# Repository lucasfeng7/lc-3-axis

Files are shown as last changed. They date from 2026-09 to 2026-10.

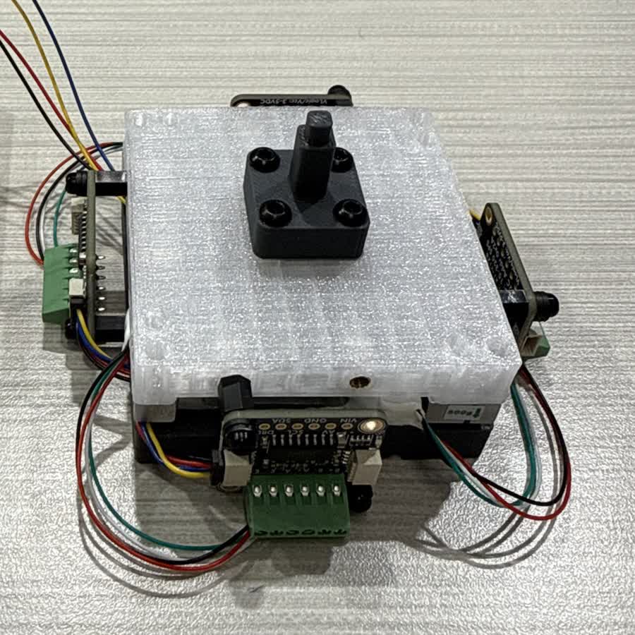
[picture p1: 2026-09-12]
docs/img/assembled.jpg

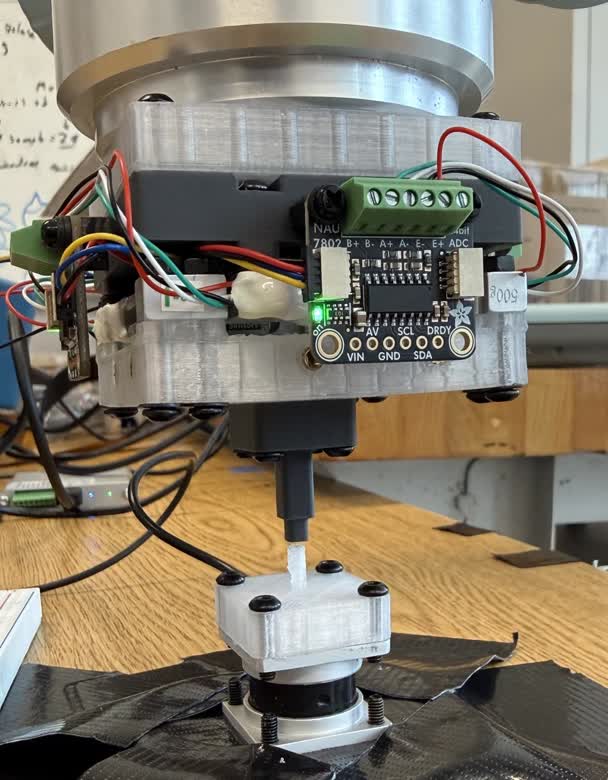
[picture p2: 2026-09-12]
docs/img/calib-optoforce.jpg

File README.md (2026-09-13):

# LC 3-Axis

An accurate three-axis force sensor assembled from off-the-shelf load cells,
with no custom compliant element.





Lucas Feng, Ariel Slepyan, Krishna Murthy, Nitish Thakor<br>
Johns Hopkins University

Presented at "Sensors and Actuators for Dexterous Manipulation: Bridging
Hardware and Application Needs," a workshop at IROS 2026 — Pittsburgh, PA.

---

## Overview

Affordable multi-axis force sensors are usually designed with a custom
compliant part, and the deformation of that part is measured after a load is
applied. Any creep, hysteresis, or thermal sensitivity in that part then
becomes a property of the finished sensor, so its accuracy depends on
operating temperature and load history in ways a single calibration cannot
capture. We instead developed a sensor using four commercial load cells that
are manufacturer-characterized to carry the full load. A single fitted
matrix maps their readings to force and accounts for assembly tolerances,
gain differences, and wiring polarity. The resulting sensor costs
\$116.55 in parts and has a 2.6–3.5 mN noise floor. Its output agrees
with a commercial reference to 1.0–2.5 % of full scale.

The full write-up, measurements, and comparison to prior work are in the
[paper](paper/lc-3-axis-iros2026.pdf) and on the
[project page](https://lucasfeng7.github.io/lc-3-axis/).

## Repository structure

```
.
├── cad/          SolidWorks source for the printed parts and top-level assembly
├── firmware/     Teensy 4.0 firmware (calibration, streaming, EEPROM storage)
├── paper/        Workshop paper (PDF)
├── media/        Demonstration video
├── docs/img/     Figures used by the project page
├── index.html    Project page (GitHub Pages)
├── CITATION.cff
└── LICENSE
```

## Bill of materials

Total **\$116.55** for the electromechanical parts below. Fasteners, cabling
and filament are excluded.

| Qty | Part | Role |
|---|---|---|
| 4 | TAL221 500 g bar load cell | the structure and the transducer, both |
| 4 | NAU7802 24-bit ADC breakout | one per cell, I²C address `0x2A` |
| 1 | TCA9548A I²C multiplexer | address `0x70`, A2:A0 to GND |
| 1 | Teensy 4.0 | reads the cells, applies the matrix, streams CSV |

Three part types are custom, and all three are FDM 3D printed.

| Part | Process | Notes |
|---|---|---|
| Upper plate | FDM, PLA | carries the tip — [`Top Plate.SLDPRT`](cad/Top%20Plate.SLDPRT) |
| Lower plate | FDM, PLA | bolts to the robot flange — [`Bottom Plate.SLDPRT`](cad/Bottom%20Plate.SLDPRT) |
| Interchangeable tip | FDM, PLA | sets contact height `h`, 38.6 mm here — [`Calibration Tip.SLDPRT`](cad/Calibration%20Tip.SLDPRT) |

No custom PCB. No machining. No cast or molded elastomer.

## CAD

SolidWorks source for the printed parts is in [`cad/`](cad/):

| File | Part |
|---|---|
| [`LC 3-Axis.SLDASM`](cad/LC%203-Axis.SLDASM) | top-level assembly |
| [`Top Plate.SLDPRT`](cad/Top%20Plate.SLDPRT) | upper plate |
| [`Bottom Plate.SLDPRT`](cad/Bottom%20Plate.SLDPRT) | lower plate |
| [`Calibration Tip.SLDPRT`](cad/Calibration%20Tip.SLDPRT) | interchangeable tip used for calibration, `h` = 38.6 mm |

The assembly references the load cells, converters and fasteners as
toolbox/purchased components, which are not included as separate files.

## How it works

Four vertical load cells connect the two 3D-printed plates in a square. Each
senses compression along the vertical axis, and together they respond to
`Fz`, `Mx`, and `My`. A lateral force is recovered from its moment about the
cell plane. For a contact at `(xc, yc)` and height `h`,

```
My = -Fx·h + Fz·xc
Mx =  Fy·h - Fz·yc
```

The contact location must therefore be known. This suits a probe with fixed
tip geometry rather than a general-purpose contact plate.

We tare each channel before loading to remove the assembly preload and the
weight of the parts above the cells. A fitted 3×4 matrix with a bias
converts the four tared counts into `(Fx, Fy, Fz)`. The same fit absorbs
placement error, cell-to-cell gain variation, and wiring polarity. Firmware
identifies the multiplexer channel used by each converter, so the physical
cell order does not matter.

## Firmware

[`firmware/lc_3_axis.ino`](firmware/lc_3_axis.ino) runs on the Teensy 4.0. It
discovers the multiplexer channels at boot, stores the calibration matrix and
the discovered channel map together in EEPROM, and refuses to load a
calibration whose map does not match the hardware present.

Libraries are Adafruit NAU7802 and Adafruit BusIO. I²C runs at 400 kHz on pins
18 and 19, with each ADC at gain 128 and 320 SPS.

Serial at 115200, newline endings. Output is plain CSV in newtons.

```
0.0142,-0.0031,1.9847
```

| key | does |
|---|---|
| `t` | re-tare, since zero drifts with temperature and the matrix does not |
| `r` | stream Fx, Fy, Fz |
| `p` | pause |
| `d` | also show the four raw cell counts |
| `u` | switch newtons and gram-force |

Lines beginning `#` are messages rather than data, so filter them when parsing.

## Calibrating

We calibrate against known masses rather than against another force sensor.
For each lateral axis, the sensor is clamped axis-horizontal at a bench edge
and known masses are hung from the tip, so gravity loads the sensing axis
perpendicular by construction. For the axial axis, a known mass is stacked
directly on the tip. The 3×4 calibration matrix is then fit against
the tared cell counts recorded at each load.

Validation against an independent reference is optional. Ours used an
OptoForce carried in series with the sensor on a UR5e, so both instruments
saw the same contact force.

## Citation

```bibtex
@inproceedings{feng2026lc3axis,
  title     = {An Accurate Three-Axis Force Sensor Assembled with Readily Available Off-the-Shelf Components with No Designed Compliant Element},
  author    = {Feng, Lucas and Slepyan, Ariel and Murthy, Krishna and Thakor, Nitish},
  booktitle = {IROS 2026 Workshop on Sensors and Actuators for Dexterous Manipulation},
  year      = {2026}
}
```

## License

MIT. See [LICENSE](LICENSE).

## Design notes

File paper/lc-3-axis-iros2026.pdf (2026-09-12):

## An Accurate Three-Axis Force Sensor Assembled with Readily Available Off-the-Shelf Components with No Designed Compliant Element

Lucas Feng, Ariel Slepyan, Krishna Murthy and Nitish Thakor Johns Hopkins University
{lfeng22, aslepya1, kmj, nitish}@jhu.edu

Abstract—Affordable multi-axis force sensors are usually designed with a custom compliant part, and the deformation of that part is measured after a load is applied. Any creep, hysteresis, or thermal sensitivity in that part then becomes a property of the finished sensor. Its accuracy then depends on operating temperature and load history in ways a single calibration cannot capture. We instead developed a sensor using four commercial load cells that are manufacturer-characterized to carry the full load. On top of the mechanical design, one fitted matrix that maps readings to force accounts for assembly tolerances, gain differences, and wiring polarity. The resulting three-axis sensor costs under $120 and has a 2.6–3.5 mN noise floor. Off-axis leakage remains below 1 %, and lateral hysteresis remains below 0.5 % of span. After one scale factor, its output agrees with a commercial reference to 1.0–2.5 % of full scale across more than 300,000 in-contact samples. The design suits tools whose contact point is known and makes an accurate three-axis sensor accessible to any research lab with a 3D printer.

I. INTRODUCTION
Force sensing is critical in any task where a robot meets a surface it cannot fully model. Commercial multi-axis sensors do this well but cost tens of thousands of dollars [1], which has pushed a research effort toward cheaper designs.
Those low-cost designs have used optical readout [2], cameras and fiducials [1], capacitance [3], and light transmitted through an elastomer [4]. In each case an inexpensive sensor measures a compliant structure built for that device. The structure determines range and sensitivity, and it also adds creep, hysteresis, and temperature dependence. These effects are seldom characterized in full. Hysteresis is sometimes reported, but creep and temperature dependence usually are not, so a user cannot predict the error under a sustained load, under load cycling, or at a different operating temperature.

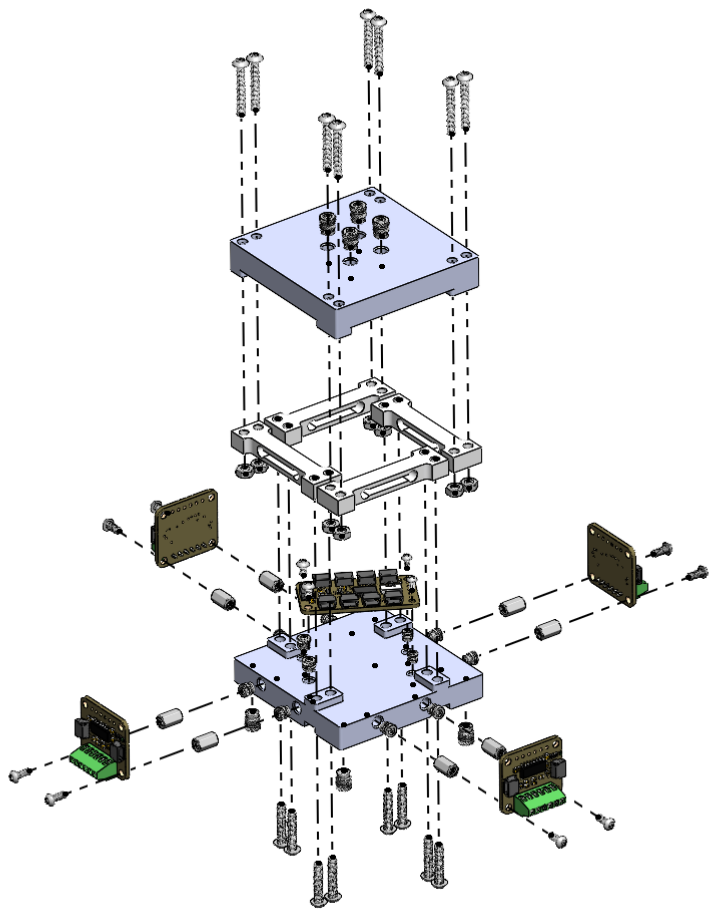
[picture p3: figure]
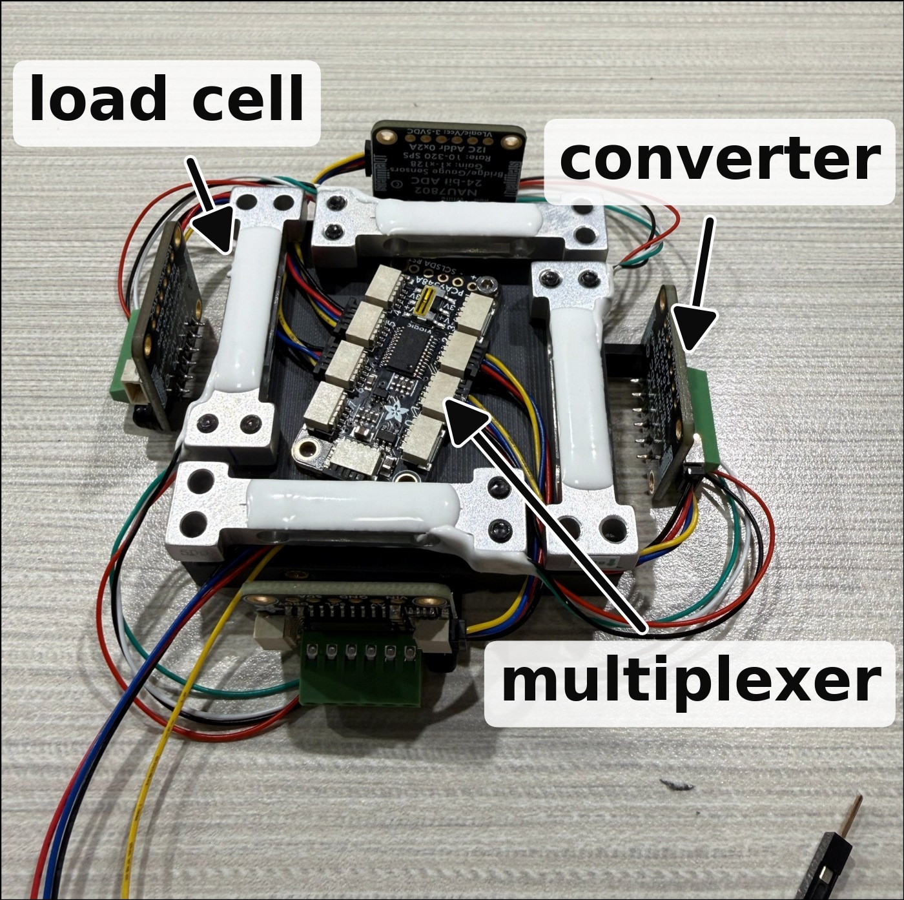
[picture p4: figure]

Fig. 1. The sensor as designed and as built. On the left, an exploded view of the body, with the interchangeable tip and the microcontroller omitted. On the right, the four load cells that form the structure, with the converters on the perimeter and the I²C multiplexer at the center.

The four-cell arrangement already exists in a design by Chua and Okamura, which places four commercial pointcontact cells around a PCB perimeter [5]. That design needs a custom PCB, which makes it far less readily available and much more expensive. Ours keeps the cost low and the error terms quantifiable while using only off-the-shelf parts. The load cells serve as both beams and transducers. Their beam geometry, strain-gauge placement and bridge compensation are set at manufacture, and the creep and temperature behavior that follows is specified on the datasheet [6], so no separate part needs its own characterization.

II. METHOD

A. Sensor Structure
Four TAL221 500 g bar load cells connect the two 3D-printed plates in a square (Fig. 1). Each senses compression along the vertical axis. Together they respond to Fz, Mx, and My. The remaining combination is the self-stress mode, a pattern of internal cell forces that cannot be produced by an external load.
Each load cell has its own NAU7802 converter, interleaved through an I²C multiplexer for an aggregate output of about 1200 Hz. The multiplexer connects to a Teensy 4.0, though any reasonably capable microcontroller would serve.
A lateral force is recovered from its moment about the cell plane. For a contact at (xc, yc) and height h, My = −Fxh + Fzxc and Mx = Fyh − Fzyc. The contact location must therefore be known. For the tests reported here, the contact face lies 38.6 mm above the cell mid-plane.
We tare each channel before loading to remove the assembly preload and the weight of the parts above the cells. A fitted 3 × 4 matrix with a bias converts a four-entry vector of tared counts into (Fx, Fy, Fz). The same fit absorbs placement error, cell-to-cell gain variation, polarity, and cross-coupling. Firmware identifies the multiplexer channel used by each converter, so the physical cell order does not matter.

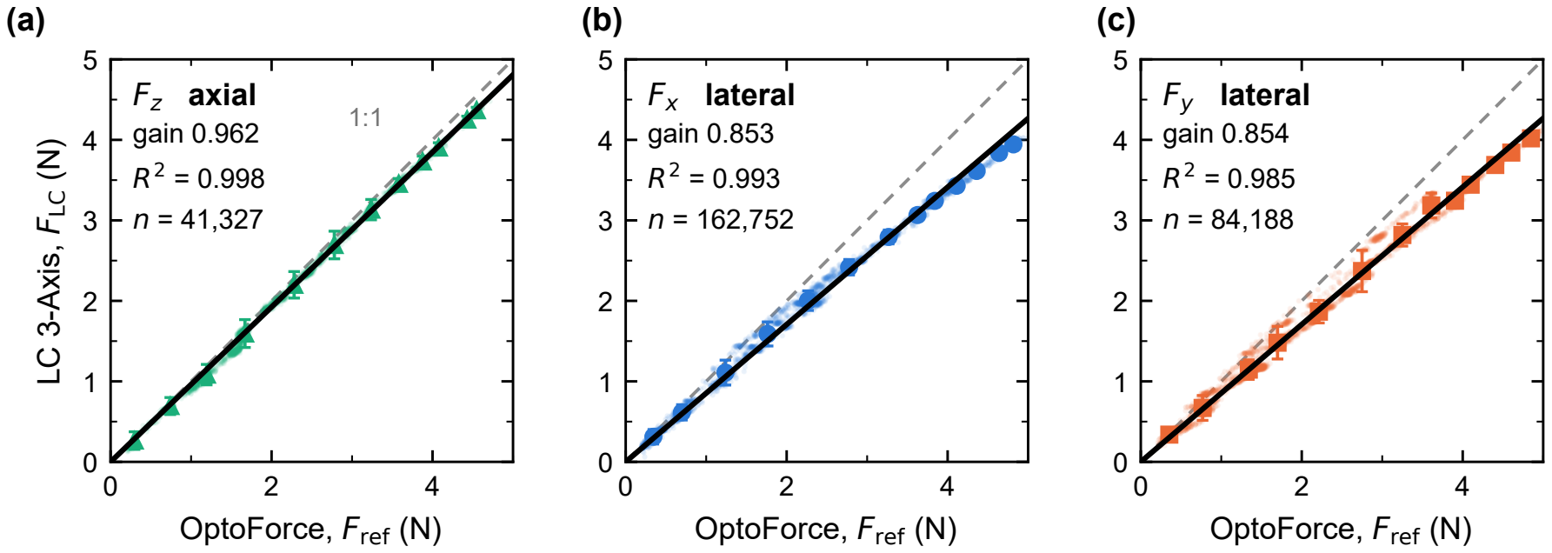
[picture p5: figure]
OptoForce, Fref (N); LC 3-Axis, FLC (N); Fz axial gain 0.962 R; Fx lateral gain 0.853 R; Fy lateral gain 0.854 R

Fig. 2. Response against the OptoForce reference with both instruments in series on the same rig. Dashed gray is the 1:1 line and black is a least-squares fit through the origin. Markers are slice means with their standard deviation. The gains and R²
shown are for the magnitude fit, which is frame-invariant. The per-axis component values quoted in the text are gains of 0.953, 0.865 and 0.873 at r

2 ≥ 0.993. The spread below 1 N in (a) is the reference’s own 0.0319 N quantization rather than sensor noise.

TABLE I
BENCH BEHAVIOR, CALIBRATED RANGE 0–4.9 N
| Fx | Fy | Fz
Leave-one-out error (N) | 0.0431 | 0.0330 | 0.0357
Noise floor, 1σ (mN) | 3.2 | 3.5 | 2.6
On-axis decoupling (%) | 100.1 | 99.7 | 99.6
Hysteresis (% of span) | 0.111 | 0.421 | 1.112

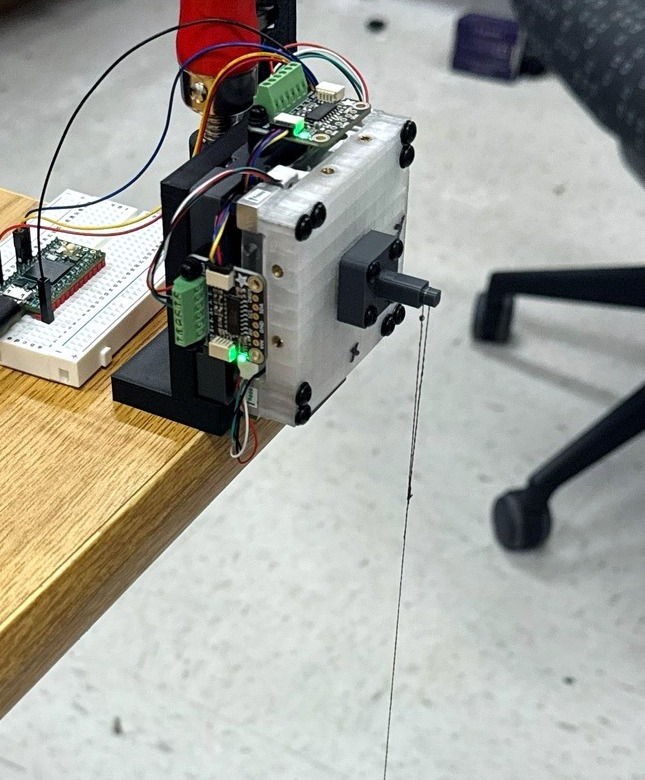
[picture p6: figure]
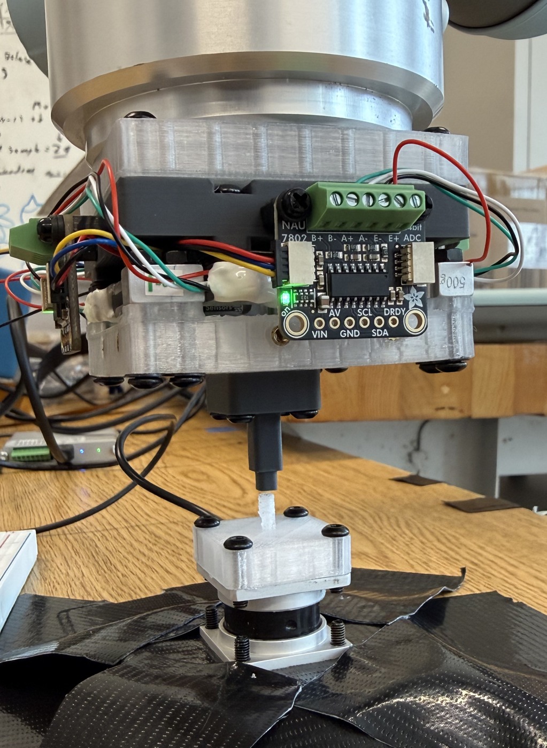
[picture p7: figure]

Fig. 3. The two calibrations. Left, the sensor clamped axis-horizontal at the bench edge with known masses hanging from the tip, so gravity loads it perpendicular to the sensing axis. Right, the two instruments in series on the UR5e, the sensor on the flange and the OptoForce below it, so each carries the same force.

B. Fabrication
Only three of the seventeen part types are custom. They are two FDM 3D-printed PLA plates and an interchangeable printed tip. The load cells, converters, multiplexer, and microcontroller cost $116.55 in total. Fasteners, cabling, and filament are excluded. The bill of materials, firmware and calibration procedure are at https://github.com/lucasfeng7/lc-3-axis.

III. EXPERIMENT

A. Sensor Characterization
We calibrated against known masses rather than another force sensor (Fig. 3). For each lateral axis the sensor was clamped horizontal, so gravity acted perpendicular to the axis being loaded.
Table I reports leave-one-out error, which stays below 0.9 % of range on every axis. Residuals measured in sample are 2.2 times smaller. On-axis decoupling is close to a full response on every axis, and the Fx entry sits just above it because of a small overshoot in the estimate. Leakage onto the other two axes stays below 1 %. Hysteresis is 0.111 % and 0.421 % of span laterally.
We applied three overloads of 19.9–28.7 N against the 19.6 N limit. After each, the unloaded output returned to within 0.05 N of zero. A different load-cell rating changes the range without changing the design.
B. Independent Validation
For validation, the UR5e carried two independently calibrated instruments in a serial stack (Fig. 3). Their coordinate frames were aligned with an orthogonal transform. The data contain 344,424 in-contact samples. The responses and fits appear in Fig. 2.
Allowing one scale factor per axis, the readings then sit within 0.1137 N of the reference on Fx and 0.1211 N on Fy,

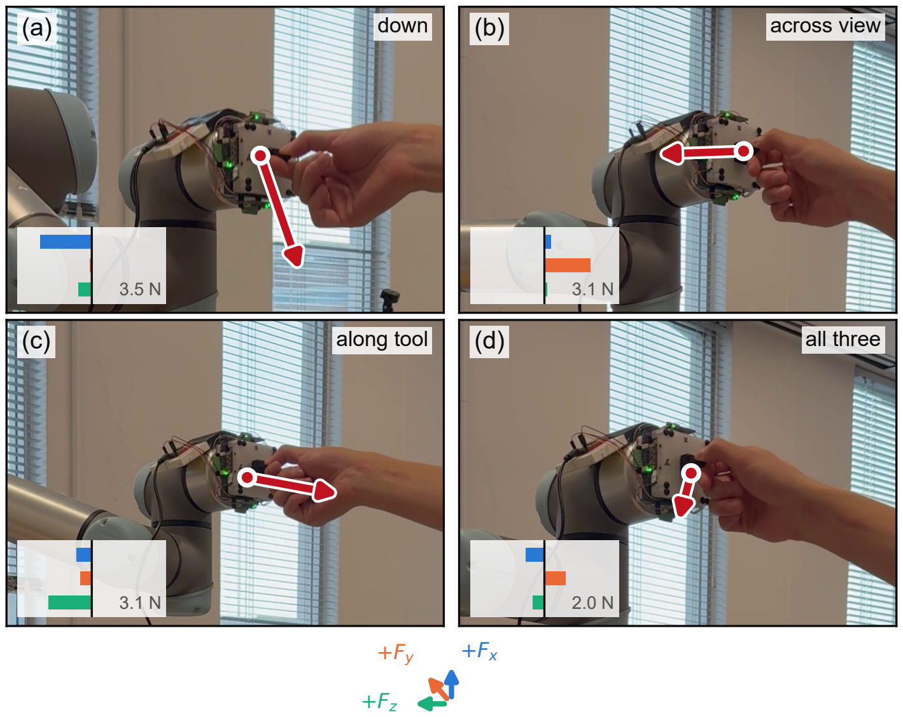
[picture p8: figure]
(a) down; (b) across view; (c) along tool; (d) all three

Fig. 4. The sensor driving admittance hand-guiding on the UR5e. Four instants from one run, with the components measured at each instant inset on a common 4.9 N scale, colored as the triad at the right. The red arrow is the measured force projected into the image from the contact point, so its length is foreshortened. Fy and Fz project within 1° of each other here, so the arrow gives the direction of a push but not its split between those two axes, which the bars carry. Panel (a) is a push down, (b) across the view, (c) along the tool, and (d) loads all three axes at once.

which is 2.32 % and 2.47 % of the 4.9 N range. The two rise together in a straight line, at r

2 ≥ 0.993. For Fz we pressed in steps of increasing force along the tool axis, where the readings sit within 0.0480 N, or 0.98 %, at r

2 = 0.998. The
scale factors themselves are 0.865 and 0.873 laterally and 0.953 axially. What separates them is scale, not scatter and not nonlinearity. The likely cause is that the robotic arm was controlled manually during the comparison, which varies the contact height and therefore the lever arm.
Even so, these figures match or exceed the closest comparable design. Both are the RMS disagreement with an independent reference after per-axis calibration constants are fitted. Ours are 0.1137 and 0.1211 N laterally and 0.0480 N axially. Chua and Okamura report 0.105 to 0.146 N laterally and 0.064 to 0.126 N axially, the spread being across the two units they built [5].
C. Sensor Applications
Finally, we used the sensor for admittance hand-guiding. In this control mode, the measured contact force commands the robot’s Cartesian velocity. The loop runs at 199.8 Hz (Fig. 4). It responds to single-axis pushes and to simultaneous loading of all three axes, which confirms that the sensor is fast and accurate enough to close a control loop on a moving robot rather than only on a bench.

IV. CONCLUSION
In this study we presented a three-axis force sensor which leverages four load cells as the structure. The sensor does not need a custom PCB and is simple to assemble, and it agrees with a commercial reference to 1.0–2.5 % of full scale. It matches or exceeds the accuracy of the closest comparable design, which makes it an affordable and easy-to-implement option for research labs that need accurate three-axis force sensing.

REFERENCES

[1] R. Ouyang and R. D. Howe, “Low-cost fiducial-based 6-axis force-torque sensor,” in IEEE International Conference on Robotics and Automation (ICRA), 2020, pp. 1–7.
[2] N. Hendrich, F. Wasserfall, and J. Zhang, “3D printed low-cost force-torque sensors,” IEEE Access, vol. 8, pp. 140 569–140 585, 2020.
[3] H. Choi et al., “CoinFT: A coin-sized, capacitive 6-axis force torque sensor,” arXiv preprint arXiv:2503.19225, 2025.
[4] A. El-Azizi, S. Islam, P. Piacenza, I. Kymissis, and M. Ciocarlie, “A compact, low-cost force and torque sensor for robot fingers with LEDbased displacement sensing,” arXiv preprint arXiv:2410.03481, 2024.
[5] Z. Chua and A. M. Okamura, “A modular 3-degrees-of-freedom force sensor for robot-assisted minimally invasive surgery research,” Sensors, vol. 23, no. 11, p. 5230, 2023.
[6] HTC Sensor, “TAL221 miniature load cell datasheet,” https://cdn.sparkfun.com/assets/9/9/a/f/3/TAL221.pdf, (https://cdn.sparkfun.com/assets/9/9/a/f/3/TAL221.pdf) 2024, creep ±0.05 % of full scale over 3 min, compensated temperature range −20 to +60 °C.

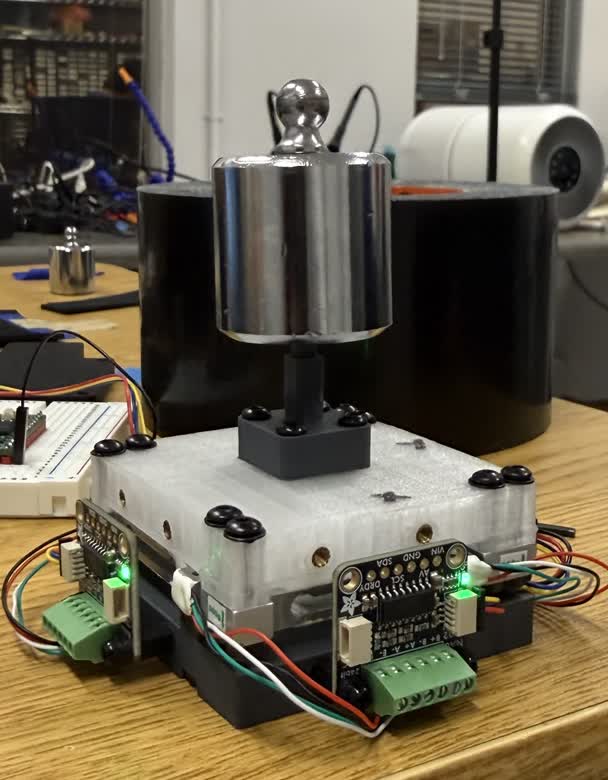
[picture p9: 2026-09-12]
docs/img/calib-axial.jpg

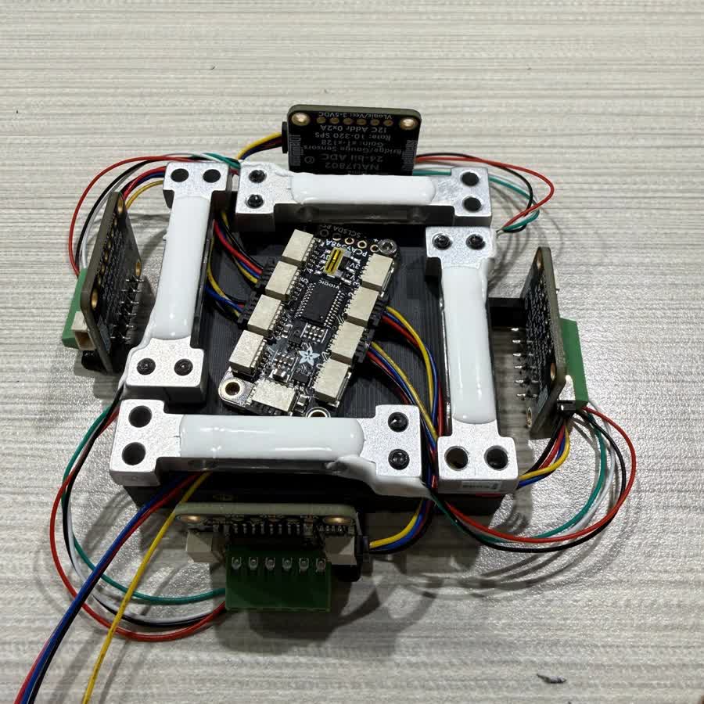
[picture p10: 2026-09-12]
docs/img/internals.jpg

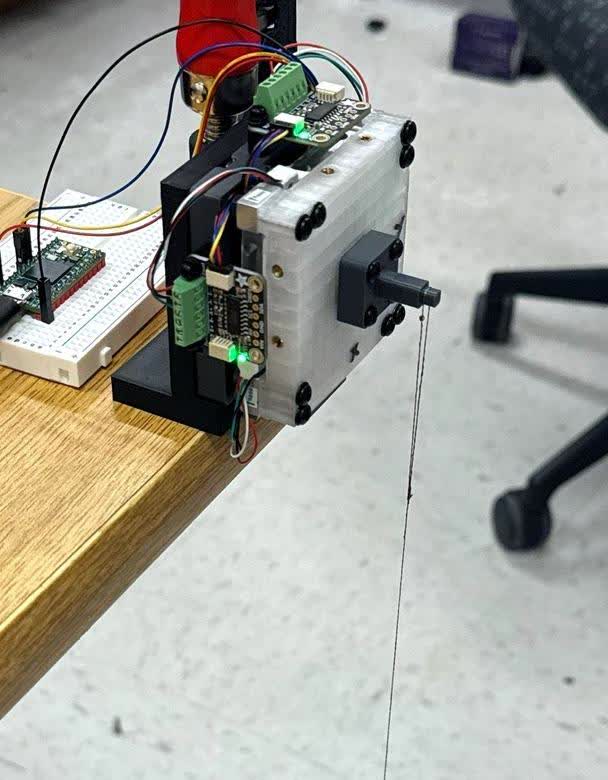
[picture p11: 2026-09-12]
docs/img/calib-deadweight.jpg

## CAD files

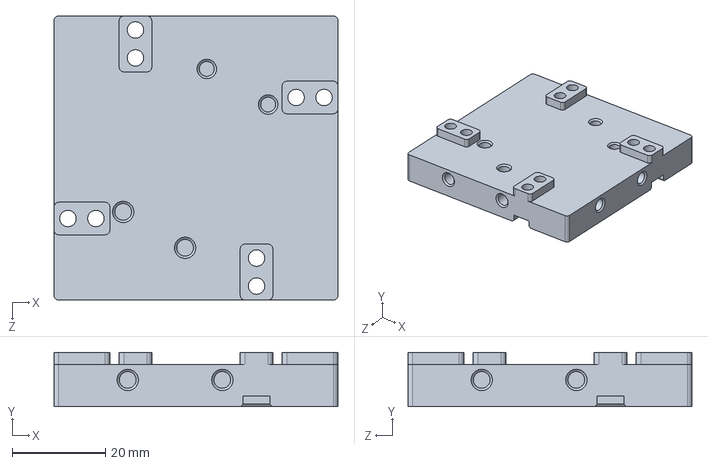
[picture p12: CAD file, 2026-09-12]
cad/Bottom Plate.SLDPRT
61.0 x 11.6 x 61.0 mm

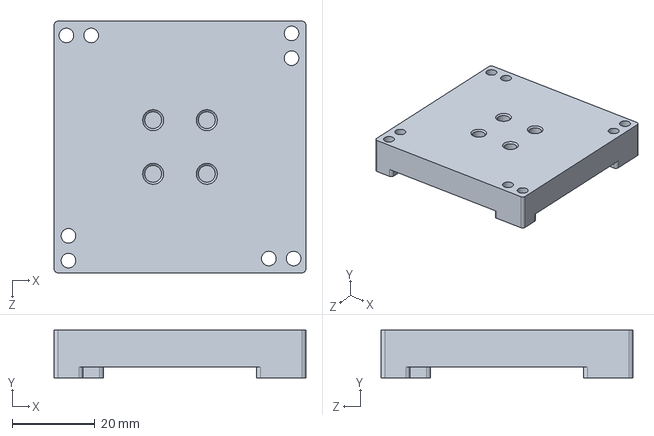
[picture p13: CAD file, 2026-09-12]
cad/Top Plate.SLDPRT
61.0 x 11.6 x 61.0 mm

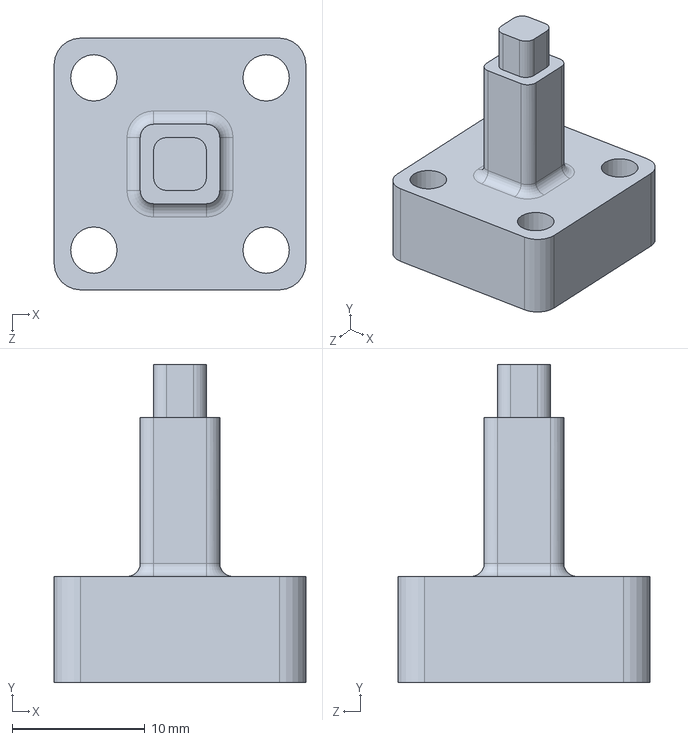
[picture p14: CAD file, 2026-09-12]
cad/Calibration Tip.SLDPRT
19.0 x 24.0 x 19.0 mm

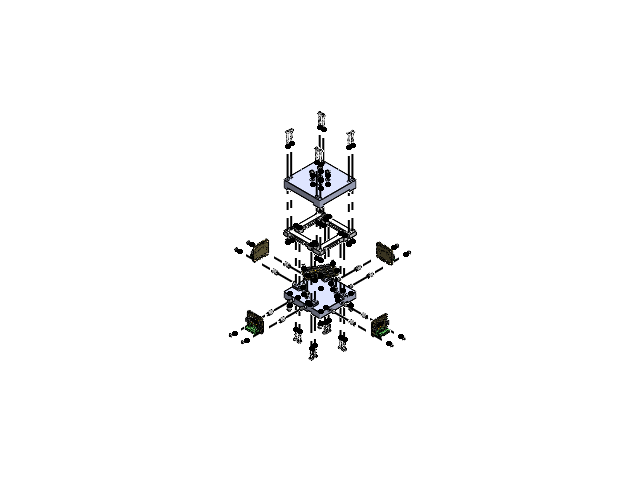
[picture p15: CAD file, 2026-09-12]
cad/LC 3-Axis.SLDASM
Bottom Plate Smaller
5626 PCA9548 Stemma
m2.5 x 10
m2 x 2
4538 NAU7802 Rev C x 4
m3_heat_set_insert x 8
92319A118_Nylon 6-6 Plastic Hex Standoff x 8
91239A811_Button Head Hex Drive Screw x 8
91239A755_Button Head Hex Drive Screw x 8
91239A753_Button Head Hex Drive Screw x 2
91239A703_Button Head Hex Drive Screw x 2
Top Plate Smaller
91239A122_Button Head Hex Drive Screw x 8
90592A085_Steel Hex Nut x 8
TAL221 500g load cell v1 x 4

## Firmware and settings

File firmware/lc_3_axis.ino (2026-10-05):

/*
 * LC 3-Axis force sensor firmware
 *
 * Target: Teensy 4.0 with a TCA9548A I2C multiplexer and four NAU7802
 * 24-bit ADCs, one per 500 g load cell.
 *
 * The four load cells provide Fz and the bending moments used to infer Fx
 * and Fy. Calibration fits a single 3x4 linear map from tared cell counts
 * to (Fx, Fy, Fz), absorbing cell gain, polarity, placement, and coupling.
 *
 * Calibration samples are zero-bracketed to reduce thermal drift. Lateral
 * calibration assumes the load is applied at the calibrated tip height;
 * off-center normal loads also generate moment and cannot be distinguished
 * from lateral force by this geometry.
 *
 * Multiplexer channels are discovered at startup and stored with calibration.
 * Serial interface: 115200 baud, newline terminated. Send 'h' for help.
 */


#include <Wire.h>
#include <EEPROM.h>
#include <Adafruit_NAU7802.h>

// Config
#define TCA_ADDR      0x70            // TCA9548A (A2:A0 = GND)
#define NAU_ADDR      0x2A            // NAU7802, fixed
#define NUM_CELLS     4
#define NPAR          5               // 4 count coefficients + 1 bias

#define I2C_HZ        400000          // within spec for both devices
#define ADC_RATE      NAU7802_RATE_320SPS
#define ADC_GAIN      NAU7802_GAIN_128

#define G0            9.80665f        // m/s^2
#define CELL_RATING_G 500.0f          // per cell; loads above the array rating are refused

#define WARMUP_DISCARD   8            // settling samples discarded after init
#define READ_TIMEOUT_MS  250
#define FRAME_TIMEOUT_MS 50           // emit a frame even if a cell stops updating
#define ACQ_TIMEOUT_MS   20000        // timeout for one averaged block

#define DEF_CAL_SAMPLES  512          // per cell, per read (512 @ 320 SPS = 1.6 s)
#define MIN_CAL_SAMPLES  64
#define MAX_CAL_SAMPLES  4096
#define NOISE_SAMPLES    512          // used at tare to measure the noise floor
#define STABLE_K         3.0          // reject a block noisier than K * tare noise
#define DRIFT_K          4.0          // reject a block trending > K sigma of its mean
#define ZERO_DRIFT_K     6.0          // warn if the bracket's two zeros disagree
#define ACQ_RETRIES      3
#define SETTLE_MS        1500         // wait for initial load-cell creep before sampling

#define MAX_SAMPLES   24              // bounded by EEPROM size, see EEPROM_BYTES
#define COUNT_SCALE   1e-6            // counts are ~1e6; scaled for conditioning
#define RIDGE_REL     1e-6            // ridge lambda, relative to mean diagonal

#define EEPROM_MAGIC  0x3A01          // change whenever the stored layout changes
#define EEPROM_ADDR   0

// State
Adafruit_NAU7802 nau;

uint8_t muxChan[NUM_CELLS];           // discovered at boot, stored with the calibration
uint8_t nFound    = 0;
int8_t  curChan   = -1;               // currently selected channel, to skip redundant writes

double  zeroCount[NUM_CELLS];         // live tare, raw counts
double  noiseSd[NUM_CELLS];           // unloaded standard deviation at tare, counts

int32_t rawCount[NUM_CELLS];          // newest streamed sample
bool    hasFresh[NUM_CELLS];

// Fx, Fy, Fz = M * counts + bias, in newtons.
// Defaults to the nominal square layout, so an uncalibrated board still
// streams output with the expected sign pattern.
float M[3][NUM_CELLS] = {
  { 1, -1, -1,  1},                   // Fx  (nominal)
  { 1,  1, -1, -1},                   // Fy  (nominal)
  { 1,  1,  1,  1},                   // Fz  = sum
};
float bias[3] = {0, 0, 0};
bool  fitted  = false;

// Types
// Keep these declarations above the first function definition because the
// Arduino build generates prototypes before compiling the sketch.

struct Sample {
  float   c[NUM_CELLS];               // zero-bracketed counts
  float   f[3];                       // applied force, newtons
  uint8_t axis;                       // 0=X 1=Y 2=Z, for reporting only
};
Sample  samples[MAX_SAMPLES];
uint8_t nSamples = 0;

// One averaged acquisition, with the statistics used by the stability check.
struct Block {
  double mean[NUM_CELLS];
  double sd[NUM_CELLS];
  double drift[NUM_CELLS];            // second-half mean minus first-half mean
};

struct FitReport {
  double rms[3];        // in-sample RMS residual, N
  double loo[3];        // leave-one-out RMS residual, N
  double worst[3];      // largest in-sample residual, N
  double ev[NUM_CELLS]; // eigenvalues of the scaled count Gram matrix, descending
  bool   ok;
};
FitReport lastFit;

// EEPROM footprint; the Teensy 4.0 provides 1080 bytes.
static const int EEPROM_BYTES = sizeof(uint16_t) + NUM_CELLS + 1 + 1
                              + NUM_CELLS * (int)sizeof(float)
                              + 3 * NUM_CELLS * (int)sizeof(float)
                              + 3 * (int)sizeof(float)
                              + MAX_SAMPLES * (int)sizeof(Sample);
static_assert(EEPROM_BYTES <= 1080, "calibration will not fit in Teensy 4.0 EEPROM");

bool     streaming  = false;
bool     showCells  = false;
bool     showStamp  = false;
bool     useNewton  = true;           // false = gram-force
float    emaAlpha   = 1.0f;           // 1 = unfiltered
uint16_t calSamples = DEF_CAL_SAMPLES;

uint32_t lastFrameMs = 0;

// Utilities
// Float formatter. %f is not reliable with newlib-nano on Teensy, and
// formatting into a buffer lets each line go out in a single Serial.write.
int fmtF(char *b, double v, int dec) {
  int i = 0;
  if (isnan(v))       { b[0] = 'n'; b[1] = 'a'; b[2] = 'n'; return 3; }
  if (fabs(v) > 1e9)  { b[0] = v < 0 ? '-' : '+'; b[1] = b[2] = b[3] = '9'; return 4; }
  if (v < 0) { b[i++] = '-'; v = -v; }
  double round = 0.5;
  for (int k = 0; k < dec; k++) round *= 0.1;
  v += round;
  uint32_t ip = (uint32_t)v;
  double   fp = v - ip;
  char t[12];
  int  n = 0;
  if (!ip) t[n++] = '0';
  while (ip) { t[n++] = '0' + ip % 10; ip /= 10; }
  while (n)  b[i++] = t[--n];
  if (dec > 0) {
    b[i++] = '.';
    for (int k = 0; k < dec; k++) {
      fp *= 10;
      int d = (int)fp;
      if (d > 9) d = 9;
      b[i++] = '0' + d;
      fp -= d;
    }
  }
  return i;
}

// Right-aligned float in a fixed-width column.
void pf(double v, int width, int dec) {
  char b[32];
  int n = fmtF(b, v, dec);
  for (int k = n; k < width; k++) Serial.print(' ');
  Serial.write(b, n);
}

float toDisplay(float newtons) { return useNewton ? newtons : newtons * 1000.0f / G0; }
const __FlashStringHelper *unitName() { return useNewton ? F("N") : F("gf"); }

// Mux
bool tcaSelect(uint8_t channel) {
  if (curChan == (int8_t)channel) return true;   // already selected
  Wire.beginTransmission(TCA_ADDR);
  Wire.write(1 << channel);
  if (Wire.endTransmission() != 0) { curChan = -1; return false; }
  curChan = channel;
  return true;
}

// ADC
bool initNAU() {
  if (!nau.begin(&Wire)) return false;
  nau.setLDO(NAU7802_3V0);
  nau.setGain(ADC_GAIN);
  nau.setRate(ADC_RATE);
  // Gain and rate changes invalidate the internal calibration, so redo it.
  nau.calibrate(NAU7802_CALMOD_INTERNAL);
  nau.calibrate(NAU7802_CALMOD_OFFSET);
  for (uint8_t i = 0; i < WARMUP_DISCARD; i++) {
    uint32_t t0 = millis();
    while (!nau.available()) if (millis() - t0 > READ_TIMEOUT_MS) return true;
    nau.read();
  }
  return true;
}

// Discover NAU7802 devices in mux-channel order. Store the channel map with
// calibration so missing hardware cannot silently change cell indexing.
bool discoverCells(bool verbose) {
  curChan = -1;
  Wire.beginTransmission(TCA_ADDR);
  if (Wire.endTransmission() != 0) {
    Serial.print(F("# TCA9548A NOT found at 0x")); Serial.println(TCA_ADDR, HEX);
    Serial.println(F("# check SDA/SCL (Teensy 4.0: 18/19), 3V3, GND, pull-ups, A0-A2"));
    nFound = 0;
    return false;
  }

  nFound = 0;
  for (uint8_t ch = 0; ch < 8 && nFound < NUM_CELLS; ch++) {
    if (!tcaSelect(ch)) continue;
    delay(2);
    Wire.beginTransmission(NAU_ADDR);
    if (Wire.endTransmission() != 0) continue;
    if (!initNAU()) continue;
    muxChan[nFound] = ch;
    zeroCount[nFound] = 0;
    noiseSd[nFound]   = 0;
    rawCount[nFound]  = 0;
    nFound++;
  }

  if (verbose) {
    Serial.print(F("# found ")); Serial.print(nFound);
    Serial.print(F(" of ")); Serial.print(NUM_CELLS); Serial.print(F(" cells on mux ch"));
    for (uint8_t c = 0; c < nFound; c++) { Serial.print(' '); Serial.print(muxChan[c]); }
    Serial.println();
    if (nFound < NUM_CELLS)
      Serial.println(F("# ! all four cells are required for 3-axis output - 'i' to rescan"));
  }
  for (uint8_t c = 0; c < NUM_CELLS; c++) hasFresh[c] = (c >= nFound);
  lastFrameMs = millis();
  return nFound == NUM_CELLS;
}

// Acquisition
// Acquire an averaged block using round-robin polling so all cells cover the
// same time window. Also compute per-cell noise and intra-block drift.
bool acquire(Block &blk, uint16_t want) {
  if (nFound == 0) return false;
  double   sum[NUM_CELLS] = {0}, sum2[NUM_CELLS] = {0}, firstSum[NUM_CELLS] = {0};
  double   ref[NUM_CELLS] = {0};
  uint16_t n[NUM_CELLS]   = {0};
  const uint16_t half = want / 2;
  uint32_t t0 = millis();

  for (;;) {
    bool done = true;
    for (uint8_t c = 0; c < nFound; c++) {
      if (n[c] >= want) continue;
      done = false;
      if (!tcaSelect(muxChan[c]) || !nau.available()) continue;
      double v = (double)nau.read();
      if (n[c] == 0) ref[c] = v;             // offset by the first reading before
      double d = v - ref[c];                 // squaring to preserve precision in sum2
      sum[c]  += d;
      sum2[c] += d * d;
      if (n[c] < half) firstSum[c] += d;
      n[c]++;
    }
    if (done) break;
    if (millis() - t0 > ACQ_TIMEOUT_MS) return false;
  }

  for (uint8_t c = 0; c < nFound; c++) {
    double m  = sum[c] / n[c];
    double var = sum2[c] / n[c] - m * m;
    blk.mean[c] = ref[c] + m;
    blk.sd[c]   = var > 0 ? sqrt(var) : 0;
    double f = firstSum[c] / half;
    double s = (sum[c] - firstSum[c]) / (n[c] - half);
    blk.drift[c] = s - f;
  }
  return true;
}

// Retry averaged reads while the signal is settling. Stability thresholds are
// relative to the noise floor measured during tare.
bool acquireStable(Block &blk, const __FlashStringHelper *what) {
  delay(SETTLE_MS);                    // allow load-cell creep to settle
  for (uint8_t attempt = 1; attempt <= ACQ_RETRIES; attempt++) {
    if (!acquire(blk, calSamples)) {
      Serial.println(F("# ! a cell stopped responding - 'i' to rescan"));
      return false;
    }
    int8_t noisy = -1, moving = -1;
    for (uint8_t c = 0; c < nFound; c++) {
      double floorSd = noiseSd[c] > 1 ? noiseSd[c] : 1;
      // K times the standard error of the difference between half-block means.
      double driftLim = DRIFT_K * blk.sd[c] * sqrt(2.0 / (calSamples / 2));
      if (driftLim < 0.5) driftLim = 0.5;
      if (blk.sd[c] > STABLE_K * floorSd)          noisy  = c;
      if (fabs(blk.drift[c]) > driftLim)           moving = c;
    }
    if (noisy < 0 && moving < 0) return true;

    Serial.print(F("# still settling ("));
    Serial.print(what);
    if (noisy >= 0) {
      Serial.print(F(", cell ")); Serial.print(noisy);
      Serial.print(F(" noise ")); pf(blk.sd[noisy], 0, 0);
      Serial.print(F(" vs ")); pf(STABLE_K * (noiseSd[noisy] > 1 ? noiseSd[noisy] : 1), 0, 0);
      Serial.print(F(" counts"));
    }
    if (moving >= 0) {
      Serial.print(F(", cell ")); Serial.print(moving);
      Serial.print(F(" drifting ")); pf(blk.drift[moving], 0, 0);
      Serial.print(F(" counts"));
    }
    Serial.print(F(") - retry ")); Serial.print(attempt);
    Serial.print('/'); Serial.println(ACQ_RETRIES);
  }
  Serial.println(F("# ! never settled - taking it anyway, treat this point with suspicion"));
  return true;
}

// Streaming
void pollCells() {
  for (uint8_t c = 0; c < nFound; c++) {
    if (!tcaSelect(muxChan[c])) continue;
    if (nau.available()) { rawCount[c] = nau.read(); hasFresh[c] = true; }
  }
}

bool frameReady() {
  for (uint8_t c = 0; c < NUM_CELLS; c++) if (!hasFresh[c]) return false;
  return true;
}

void applyMatrix(const float c[NUM_CELLS], float f[3]) {
  for (uint8_t r = 0; r < 3; r++) {
    double a = bias[r];
    for (uint8_t i = 0; i < NUM_CELLS; i++) a += (double)M[r][i] * c[i];
    f[r] = (float)a;
  }
}

// Apply the matrix and the EMA filter, then send one CSV frame.
void emitFrame() {
  static float filt[3] = {0, 0, 0};
  static bool  primed  = false;

  float c[NUM_CELLS], f[3];
  for (uint8_t i = 0; i < NUM_CELLS; i++) c[i] = (float)(rawCount[i] - zeroCount[i]);
  applyMatrix(c, f);

  if (!primed) { for (uint8_t r = 0; r < 3; r++) filt[r] = f[r]; primed = true; }
  else for (uint8_t r = 0; r < 3; r++) filt[r] += emaAlpha * (f[r] - filt[r]);

  char buf[160];
  int  n = 0;
  if (showStamp) n += snprintf(buf + n, sizeof(buf) - n, "%lu,", (unsigned long)micros());
  for (uint8_t r = 0; r < 3; r++) {
    n += fmtF(buf + n, toDisplay(filt[r]), 4);
    buf[n++] = (r < 2 || showCells) ? ',' : '\n';
  }
  if (showCells)
    for (uint8_t i = 0; i < NUM_CELLS; i++)
      n += snprintf(buf + n, sizeof(buf) - n, "%ld%c", (long)(rawCount[i] - (long)zeroCount[i]),
                    i < NUM_CELLS - 1 ? ',' : '\n');
  Serial.write(buf, n);

  for (uint8_t c2 = 0; c2 < NUM_CELLS; c2++) hasFresh[c2] = (c2 >= nFound);
  lastFrameMs = millis();
}

// Tare
// Tare all cells and record each cell's noise floor, which the stability
// checks are scaled against.
void tareAll() {
  Serial.println(F("# taring - keep the sensor UNLOADED and still"));
  Block b;
  if (!acquire(b, NOISE_SAMPLES)) { Serial.println(F("# ! tare failed")); return; }
  for (uint8_t c = 0; c < nFound; c++) { zeroCount[c] = b.mean[c]; noiseSd[c] = b.sd[c]; }

  Serial.println(F("# cell      zero     noise sd"));
  for (uint8_t c = 0; c < nFound; c++) {
    Serial.print(F("#    ")); Serial.print(c);
    pf(zeroCount[c], 11, 0);
    pf(noiseSd[c], 11, 1);
    Serial.println();
  }
  if (fitted) {
    // Propagate independent cell noise through each force row in quadrature.
    const char *nm[3] = {"Fx ", "  Fy ", "  Fz "};
    Serial.print(F("# 1-sigma single-sample resolution ~ "));
    for (uint8_t r = 0; r < 3; r++) {
      double q = 0;
      for (uint8_t i = 0; i < nFound; i++) {
        const double t = (double)M[r][i] * noiseSd[i];
        q += t * t;
      }
      Serial.print(nm[r]);
      pf(toDisplay((float)sqrt(q)), 0, 4);
    }
    Serial.print(' '); Serial.println(unitName());
  }
  for (uint8_t c = 0; c < NUM_CELLS; c++) hasFresh[c] = (c >= nFound);
  lastFrameMs = millis();
}

// Unloaded drift test. Reports each cell's drift rate in counts/s, so a cell
// that drifts on its own can be identified before calibration rather than
// through rejected samples.
void driftTest(uint16_t seconds) {
  if (nFound == 0) { Serial.println(F("# ! no cells")); return; }

  Serial.print(F("# --- drift test, ")); Serial.print(seconds);
  Serial.println(F(" s. UNLOADED, hands off, any key stops. ---"));
  Block b;
  if (!acquire(b, 320)) { Serial.println(F("# ! read failed")); return; }

  double first[NUM_CELLS], last[NUM_CELLS], lo[NUM_CELLS], hi[NUM_CELLS];
  for (uint8_t c = 0; c < nFound; c++)
    first[c] = last[c] = lo[c] = hi[c] = b.mean[c];

  const uint32_t t0 = millis();
  Serial.println(F("#    t/s        c0        c1        c2        c3   (change from start)"));
  while ((millis() - t0) / 1000 < seconds) {
    if (Serial.available()) { while (Serial.available()) Serial.read(); break; }
    if (!acquire(b, 320)) break;                 // ~1 s per row
    Serial.print(F("# ")); pf((millis() - t0) / 1000.0, 6, 0);
    for (uint8_t c = 0; c < nFound; c++) {
      last[c] = b.mean[c];
      if (b.mean[c] < lo[c]) lo[c] = b.mean[c];
      if (b.mean[c] > hi[c]) hi[c] = b.mean[c];
      pf(last[c] - first[c], 10, 0);
    }
    Serial.println();
  }

  const double el = (millis() - t0) / 1000.0;
  if (el < 1) return;
  Serial.println(F("# cell     total      rate      span   verdict"));
  double worstRate = 0;
  int8_t worstCell = -1;
  for (uint8_t c = 0; c < nFound; c++) {
    const double rate = (last[c] - first[c]) / el;
    Serial.print(F("#    ")); Serial.print(c);
    pf(last[c] - first[c], 10, 0);
    pf(rate, 10, 1);
    pf(hi[c] - lo[c], 10, 0);
    // Flag a cell whose net drift over the test exceeds 3x its noise floor.
    Serial.println(fabs(rate) * el > 3 * (noiseSd[c] > 1 ? noiseSd[c] : 1)
                   ? F("   DRIFTING") : F("   ok"));
    if (fabs(rate) > fabs(worstRate)) { worstRate = rate; worstCell = c; }
  }
  Serial.println(F("#   total/span in counts, rate in counts/s"));
  if (worstCell >= 0 && fabs(worstRate) * el > 3 * (noiseSd[worstCell] > 1 ? noiseSd[worstCell] : 1)) {
    Serial.print(F("#   ! cell ")); Serial.print(worstCell);
    Serial.println(F(" is the worst. Swap its load cell onto another NAU7802:"));
    Serial.println(F("#     drift follows the CELL = cell/wiring, stays on the BOARD = ADC."));
  }
}

// Linear algebra
// Gauss-Jordan inverse of a small symmetric positive-definite matrix. The
// full inverse, not just a solve, is needed for the leave-one-out residuals.
bool invertN(double A[NPAR][NPAR], double inv[NPAR][NPAR]) {
  double a[NPAR][2 * NPAR];
  for (uint8_t i = 0; i < NPAR; i++) {
    for (uint8_t j = 0; j < NPAR; j++) { a[i][j] = A[i][j]; a[i][NPAR + j] = (i == j); }
  }
  for (uint8_t col = 0; col < NPAR; col++) {
    uint8_t piv = col;
    for (uint8_t r = col + 1; r < NPAR; r++)
      if (fabs(a[r][col]) > fabs(a[piv][col])) piv = r;
    if (fabs(a[piv][col]) < 1e-18) return false;
    if (piv != col) for (uint8_t k = 0; k < 2 * NPAR; k++) {
      double s = a[col][k]; a[col][k] = a[piv][k]; a[piv][k] = s;
    }
    double d = a[col][col];
    for (uint8_t k = 0; k < 2 * NPAR; k++) a[col][k] /= d;
    for (uint8_t r = 0; r < NPAR; r++) {
      if (r == col) continue;
      double fac = a[r][col];
      if (fac == 0) continue;
      for (uint8_t k = 0; k < 2 * NPAR; k++) a[r][k] -= fac * a[col][k];
    }
  }
  for (uint8_t i = 0; i < NPAR; i++)
    for (uint8_t j = 0; j < NPAR; j++) inv[i][j] = a[i][NPAR + j];
  return true;
}

// Cyclic Jacobi eigenvalues of a 4x4 symmetric matrix, sorted descending.
// Used only to report how well the sample set spans the measurable space.
void eigenvalues4(const double Ain[NUM_CELLS][NUM_CELLS], double ev[NUM_CELLS]) {
  double a[NUM_CELLS][NUM_CELLS];
  for (uint8_t i = 0; i < NUM_CELLS; i++)
    for (uint8_t j = 0; j < NUM_CELLS; j++) a[i][j] = Ain[i][j];

  for (uint8_t sweep = 0; sweep < 30; sweep++) {
    double off = 0;
    for (uint8_t p = 0; p < NUM_CELLS; p++)
      for (uint8_t q = p + 1; q < NUM_CELLS; q++) off += a[p][q] * a[p][q];
    if (off < 1e-30) break;
    for (uint8_t p = 0; p < NUM_CELLS; p++) {
      for (uint8_t q = p + 1; q < NUM_CELLS; q++) {
        if (fabs(a[p][q]) < 1e-300) continue;
        double theta = (a[q][q] - a[p][p]) / (2 * a[p][q]);
        double t = (theta >= 0 ? 1.0 : -1.0) / (fabs(theta) + sqrt(theta * theta + 1));
        double c = 1 / sqrt(t * t + 1), s = t * c;
        for (uint8_t k = 0; k < NUM_CELLS; k++) {
          double akp = a[k][p], akq = a[k][q];
          a[k][p] = c * akp - s * akq;
          a[k][q] = s * akp + c * akq;
        }
        for (uint8_t k = 0; k < NUM_CELLS; k++) {
          double apk = a[p][k], aqk = a[q][k];
          a[p][k] = c * apk - s * aqk;
          a[q][k] = s * apk + c * aqk;
        }
      }
    }
  }
  for (uint8_t i = 0; i < NUM_CELLS; i++) ev[i] = a[i][i];
  for (uint8_t i = 0; i < NUM_CELLS; i++)          // sort descending
    for (uint8_t j = i + 1; j < NUM_CELLS; j++)
      if (ev[j] > ev[i]) { double s = ev[i]; ev[i] = ev[j]; ev[j] = s; }
}
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
void loop() {
  serviceSerial();
  if (!streaming || nFound == 0) return;

  pollCells();
  if (frameReady()) {
    emitFrame();
  } else if (millis() - lastFrameMs > FRAME_TIMEOUT_MS) {
    emitFrame();                                // a cell stopped updating; keep the stream alive
  }
}

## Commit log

2026-08-31 Add Teensy 4.0 firmware and serial interface docs
2026-09-12 Add SolidWorks CAD files and rebuild project page with Bulma
    [Calibration Tip.SLDPRT, LC 3-Axis.SLDASM, Top Plate Smaller.SLDPRT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]
2026-09-12 Align README and project page with the paper; fix CAD files
    Swap the mislabeled plate part for the correct top/bottom pair,
    replace the exploded render with a photo of the assembled sensor,
    and crop the demo video to landscape.
    [Bottom Plate.SLDPRT, Top Plate Smaller.SLDPRT, Top Plate.SLDPRT]
2026-09-12 Add axial calibration photo and fit calibration photos in one row
2026-09-12 Recenter the axial calibration and assembled-sensor photos
2026-09-12 Rework README as a concise build and reference guide
    Leave the full write-up to the paper and project page. Keep an
    overview, repository layout, bill of materials, CAD, firmware and
    calibration notes, add license, paper and project page badges, and
    drop the two figures that are no longer referenced.
